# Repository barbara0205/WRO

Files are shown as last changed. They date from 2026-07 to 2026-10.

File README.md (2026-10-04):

# MechaMinds-WRO 2026 Future Engineers
# WRO Future Engineers - Engineering Documentation
<p align="center">
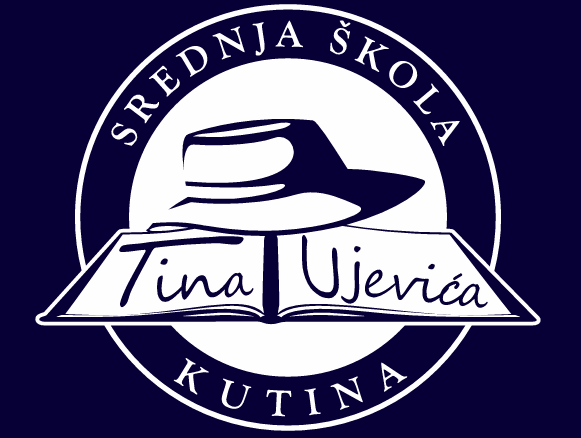
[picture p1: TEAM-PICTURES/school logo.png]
 
<br>
<em> Our school logo.</em>
</p>

## Team Members
- **Barbara Lukić**
- **Nadia Kravčuk**
- **Ivano Koren**

<p align="center">
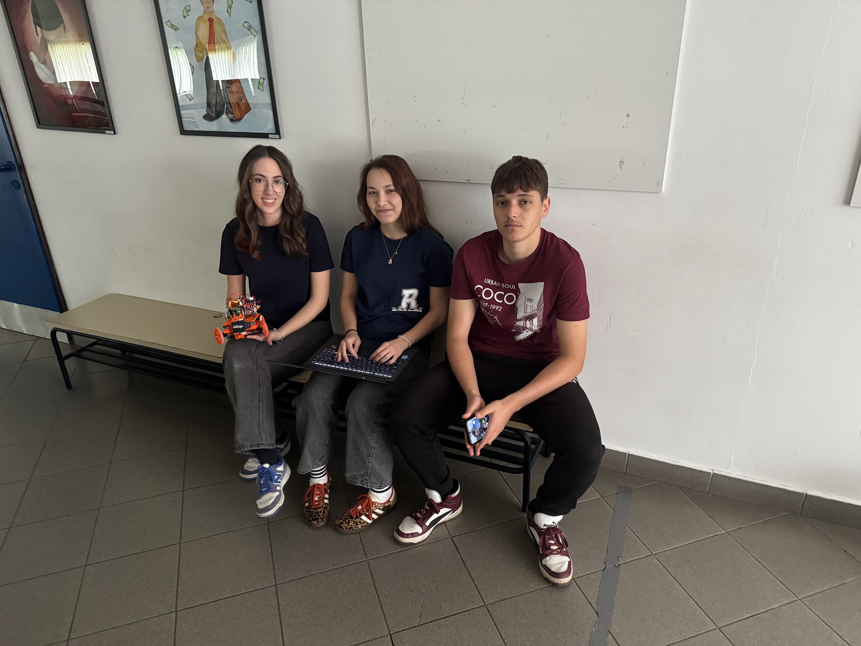
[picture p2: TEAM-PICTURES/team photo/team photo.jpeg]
  
</p>
<br>
<p align="center">
  <em>Team picture.</em>
</p>
<p align="center">
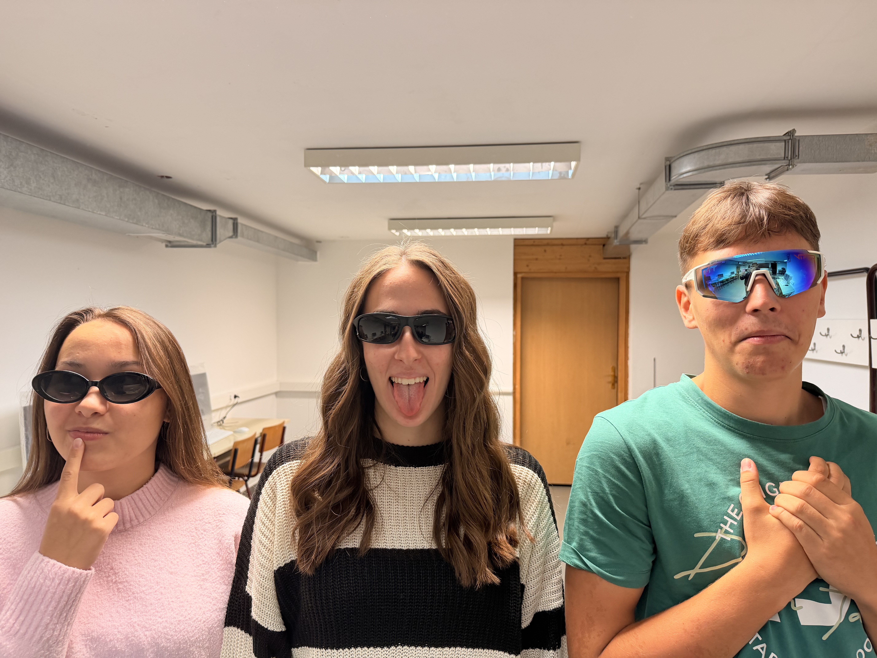
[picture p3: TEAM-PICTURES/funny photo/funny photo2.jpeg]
   
</p>
<br>
<p align="center">
  <em>Funny team picture.</em>
</p>

[Watch the introduction video](TEAM-PICTURES/video/video_mechaminds.mp4)

## Table of Contents

- [1. Project Overview](#1-project-overview)
- [2. Team](#2-team)
- [3. Vehicle Overview](#3-vehicle-overview)

- [4. Development History](#4-development-history)
  - [4.1 Version 1](#41-version-1)
  - [4.2 Version 2](#42-version-2)
  - [4.3 Version 3](#43-version-3)
  - [4.4 Version 4](#44-version-4)

- [5. Current Robot](#5-current-robot)
 
- [6. Mobility & Mechanical Design](#6-mobility--mechanical-design)
  - [6.1 Chassis](#61-chassis)
  - [6.2 Steering & Driving System](#62-steering--driving-system)
  - [6.3 Dimensions and Weight](#63-dimensions-and-weight)
  
- [7. Power & Sensor Architecture](#7-power--sensor-architecture)
  - [7.1 Motors](#71-motors)
  - [7.2 Sensors](#72-sensors)
  - [7.3 Camera](#73-camera)
  - [7.4 Wiring Diagram](#74-wiring-diagram)
  - [7.5 Power](#75-power)
  - [7.6 ON/OFF Button](#76-onoff-button)
  
- [8. Software Architecture](#8-software-architecture)
  - [8.1 Overview](#81-overview)
  - [8.2 Code](#82-code)
  - [8.3 Open Challenge Strategy](#83-open-challenge-strategy)
  - [8.4 Obstacle Challenge Strategy](#84-obstacle-challenge-strategy)
    
- [9. Engineering Decisions](#9-engineering-decisions)
  - [9.1 Major Problems and Solutions](#91-major-problems-and-solutions)

- [10. Testing & Results](#10-testing--results)

- [11. Components / Bill of Materials](#11-components--bill-of-materials)

- [12. Build & Reproduction Guide](#12-build--reproduction-guide)
  - [12.1 Parts](#121-parts)
  - [12.2 Assembly](#122-assembly)

- [13. Repository Structure](#13-repository-structure)
- [14. Engineering Journal](#14-engineering-journal)

## 1. Project Overview
Our project is an autonomous vehicle that can navigate the competition field, detect and avoid obstacles, follow the track and make real time decisions without human intervention.

<p align="right">
  <a href="#table-of-contents">⬆ Back to Table of Contents</a>
</p>

## 2. Team
We are the Croatian robotics team **MechaMinds** and our names are **Barbara Lukić**, **Ivano Koren** and **Nadia Kravčuk**. We come from Tin Ujević High School in Kutina. Our mentor's name is Damir Petravić. Together we worked on the design of the robot, programming and testing our robot.

<p align="right">
  <a href="#table-of-contents">⬆ Back to Table of Contents</a>
</p>

## 3. Vehicle Overview
| Specification | Value |
|---|---|
| Length | 18 cm |
| Width | 17.5 cm |
| Height | 15.5 cm |
| Weight | 0.876 kg |
| Drive type | Rear-wheel drive |
| Steering type | Ackermann steering | ---Servo-controlled front steering???
| Main controller | Raspberry Pi 5 Model (B Rev1.1) |
| Programming language | C++ |
| Main sensors | MRMS LIDAR 2 m (VL53L0CX), CAN Bus |
| Camera | Raspberry Pi Camera Module 3 |
| Power source | Turnigy 5S LiPo, 18.5 V, 5000 mAh |

<p align="right">
  <a href="#table-of-contents">⬆ Back to Table of Contents</a>
</p>

## 4. Development history 
Our robot went through several major design changes during the development process. 
### 4.1. Version 1 
**About the robot** 
  - Our first robot was a custom-built vehicle made using 3D-printed and hand-built parts. It had several distance sensors that helped us test the robot.

**Main problem** 
  - The robot was not reliable enough to complete three laps so we decided to change the robot for better performance.

| Front | Rear |
|---|---|
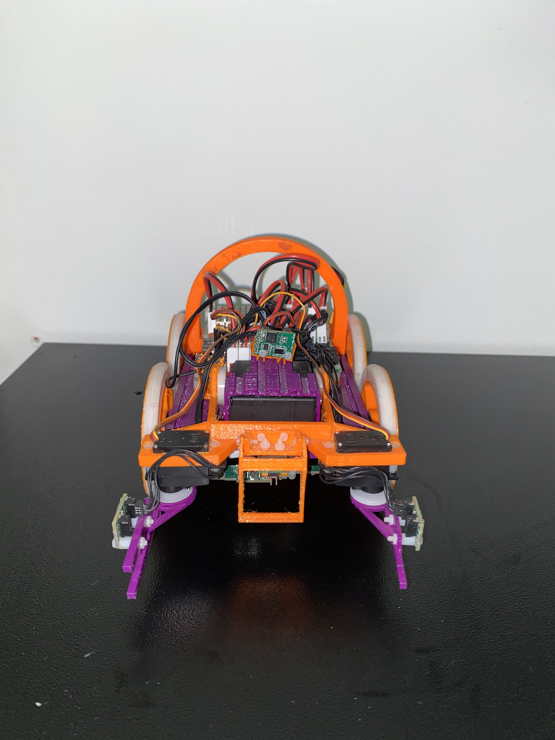
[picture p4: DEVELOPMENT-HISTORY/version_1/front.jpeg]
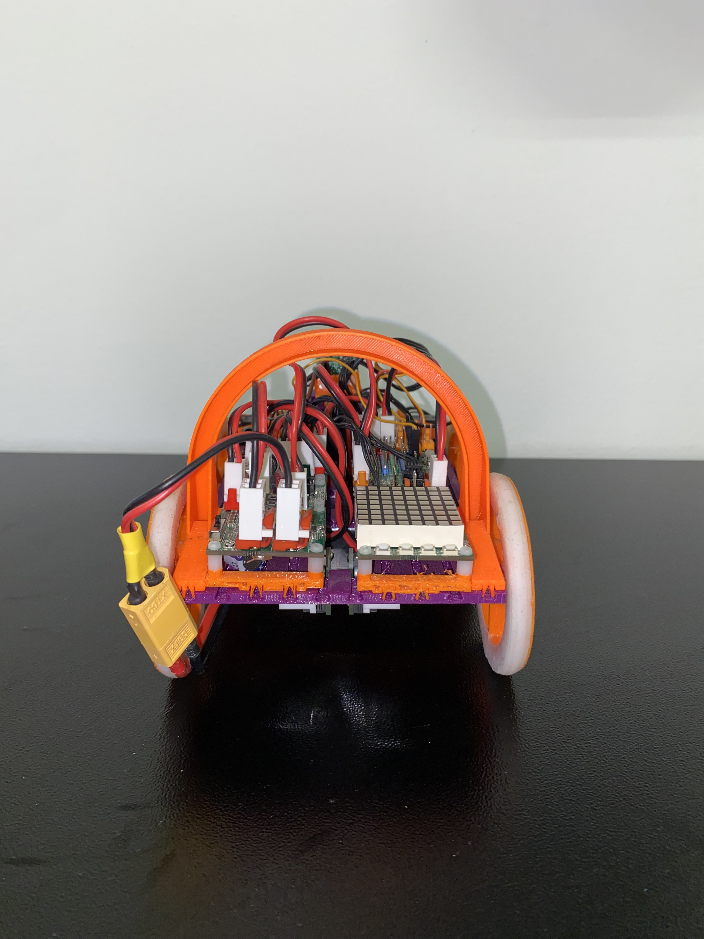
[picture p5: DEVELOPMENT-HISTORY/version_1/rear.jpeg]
|  |  |

| Left | Right |
|---|---|
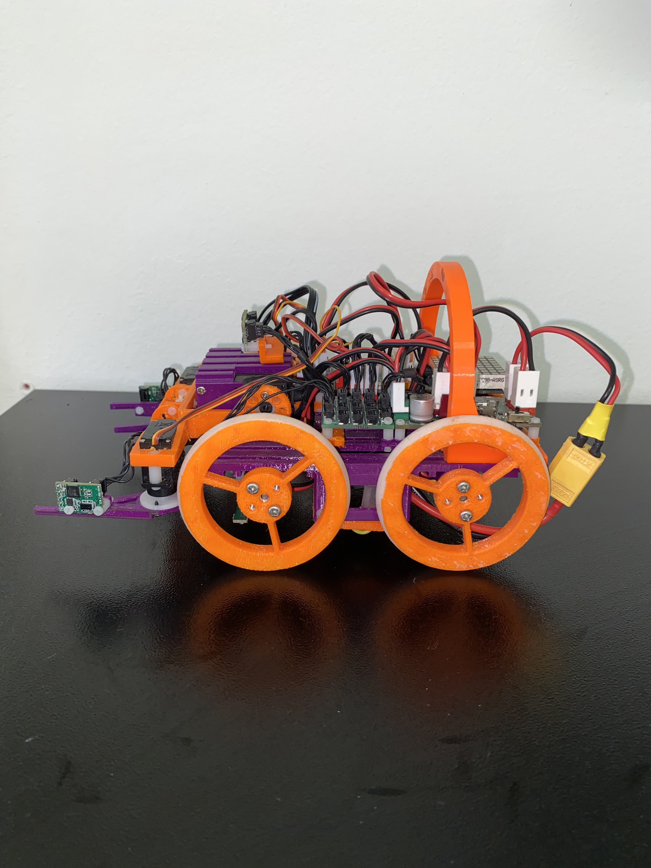
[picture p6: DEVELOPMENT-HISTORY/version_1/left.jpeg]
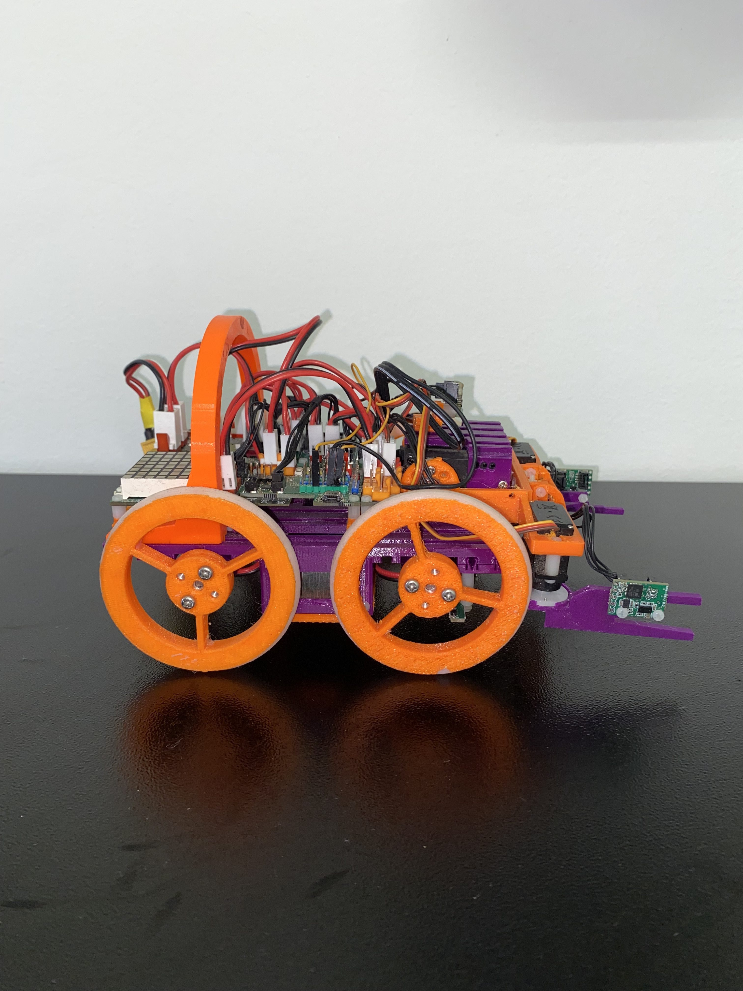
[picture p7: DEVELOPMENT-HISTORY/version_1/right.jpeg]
|  |  |

| Top | Bottom |
|---|---|
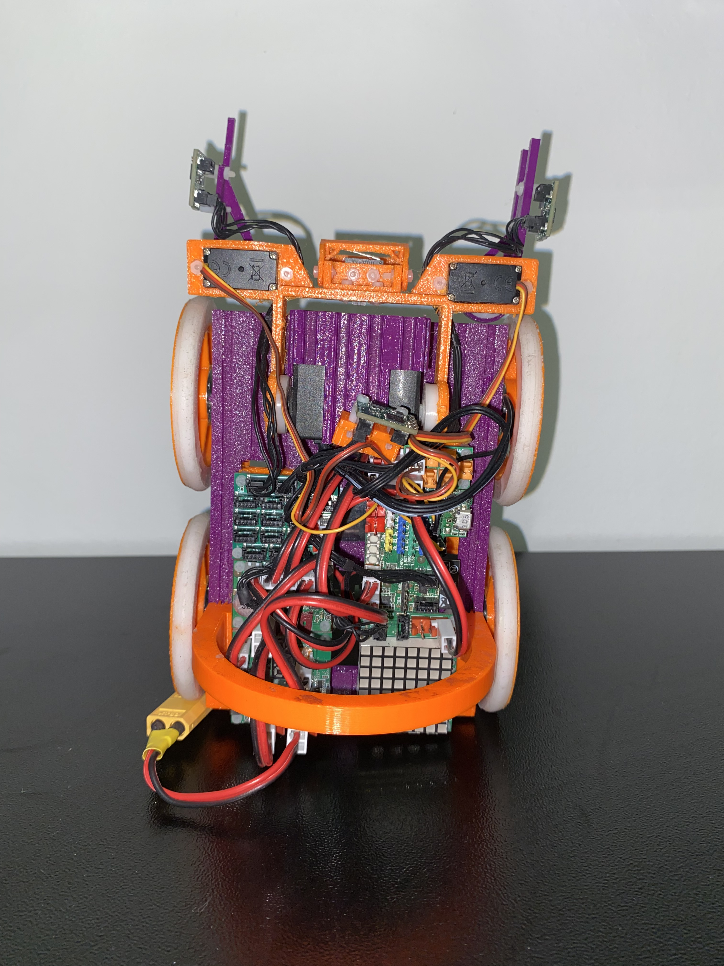
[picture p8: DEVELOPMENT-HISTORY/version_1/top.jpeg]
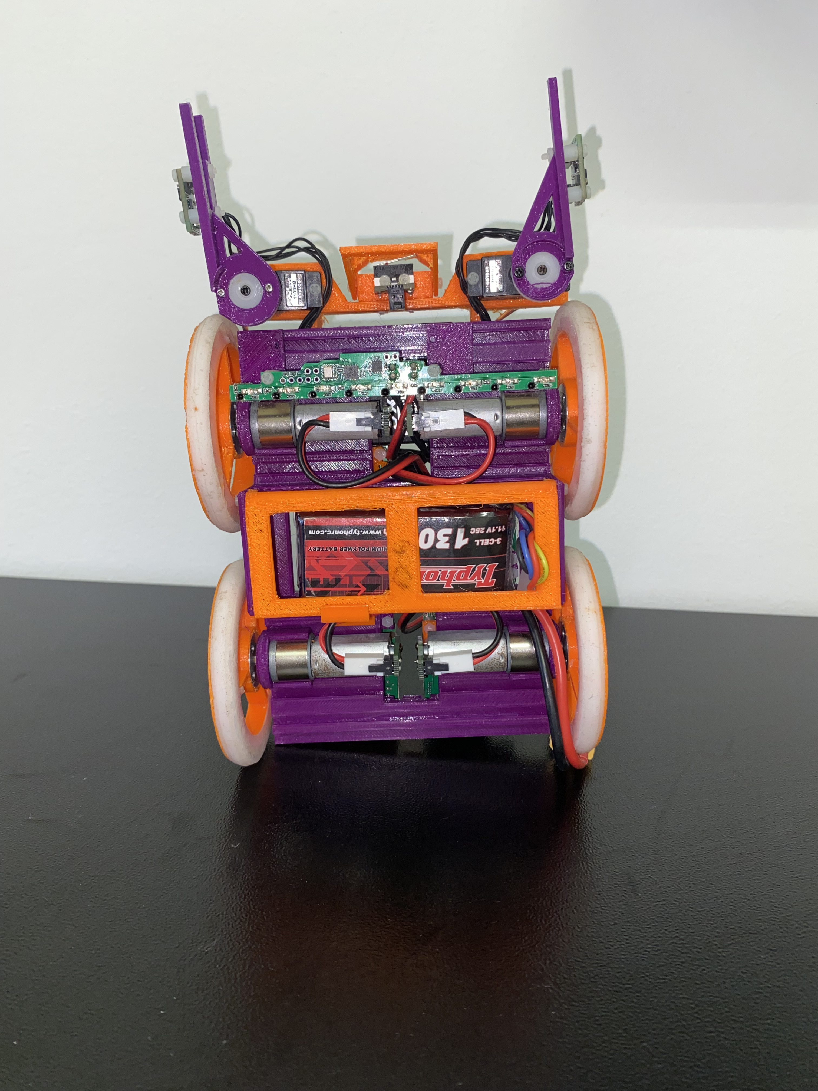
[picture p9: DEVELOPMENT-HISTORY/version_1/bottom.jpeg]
|  |  |

<p align="right">
  <a href="#table-of-contents">⬆ Back to Table of Contents</a>
</p>

### 4.2. Version 2
**About the robot**
- This robot was an upgraded version of the first one, it had a camera and several distance sensors.
  
**Main problem**
- All year we have been working on this robot, about one month before the competition we started having problems connecting the robot to Wi-Fi, it started crashing and we tried to find a solution before the competition but we did not succeed.

| Front | Rear |
|---|---|
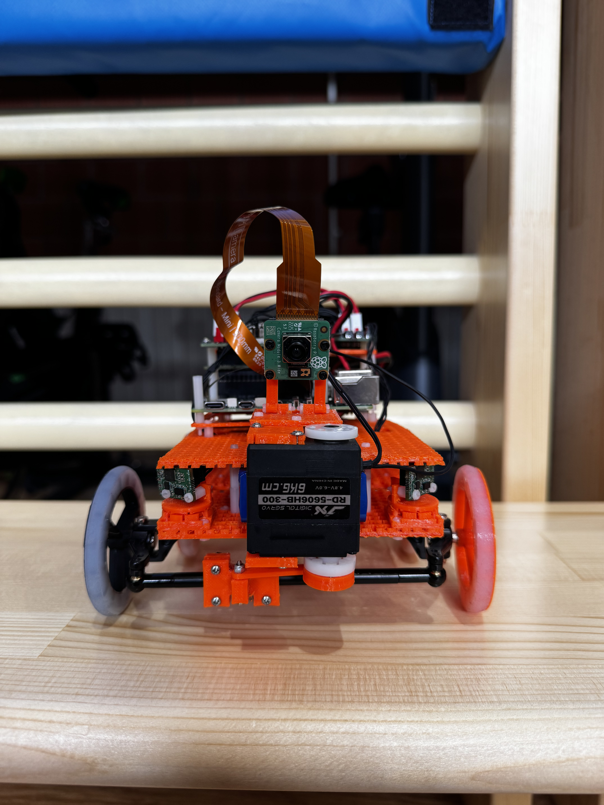
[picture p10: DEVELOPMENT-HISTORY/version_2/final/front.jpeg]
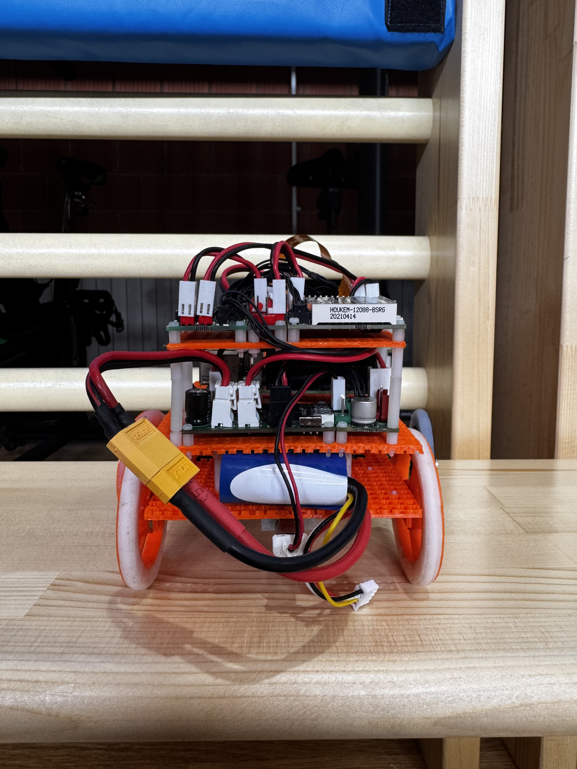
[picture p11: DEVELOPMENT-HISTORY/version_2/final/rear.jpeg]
|  |  |

| Left | Right |
|---|---|
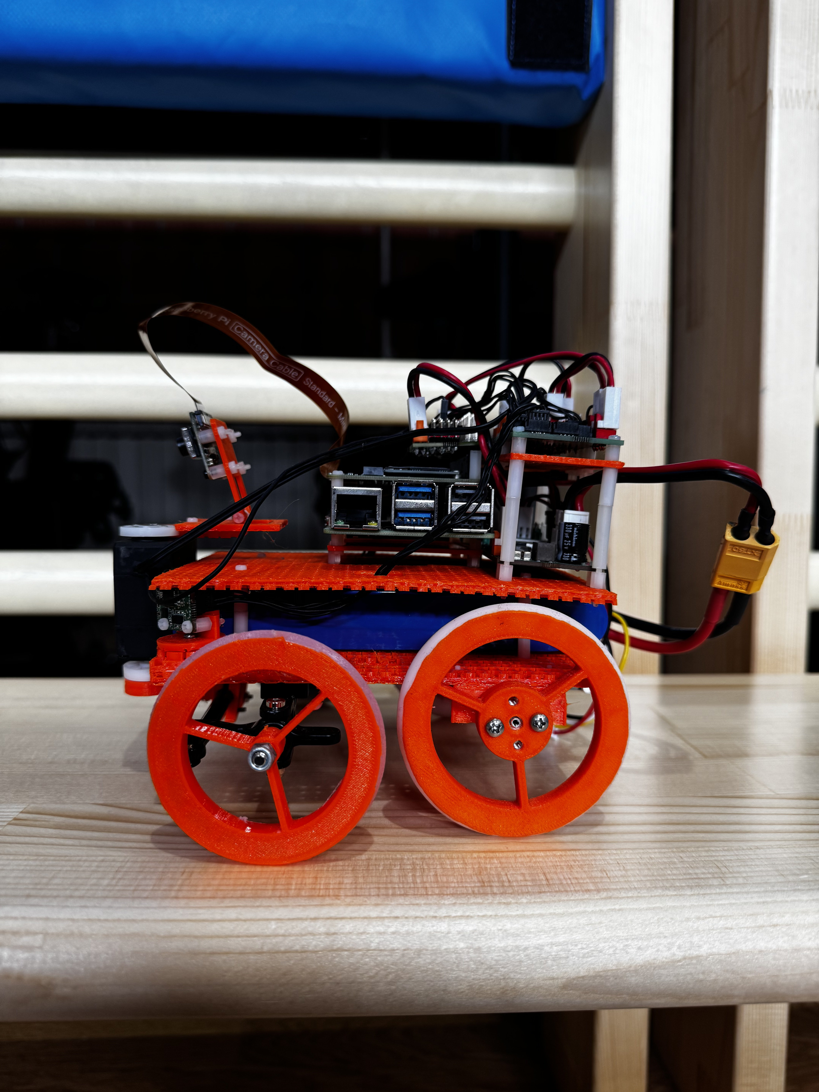
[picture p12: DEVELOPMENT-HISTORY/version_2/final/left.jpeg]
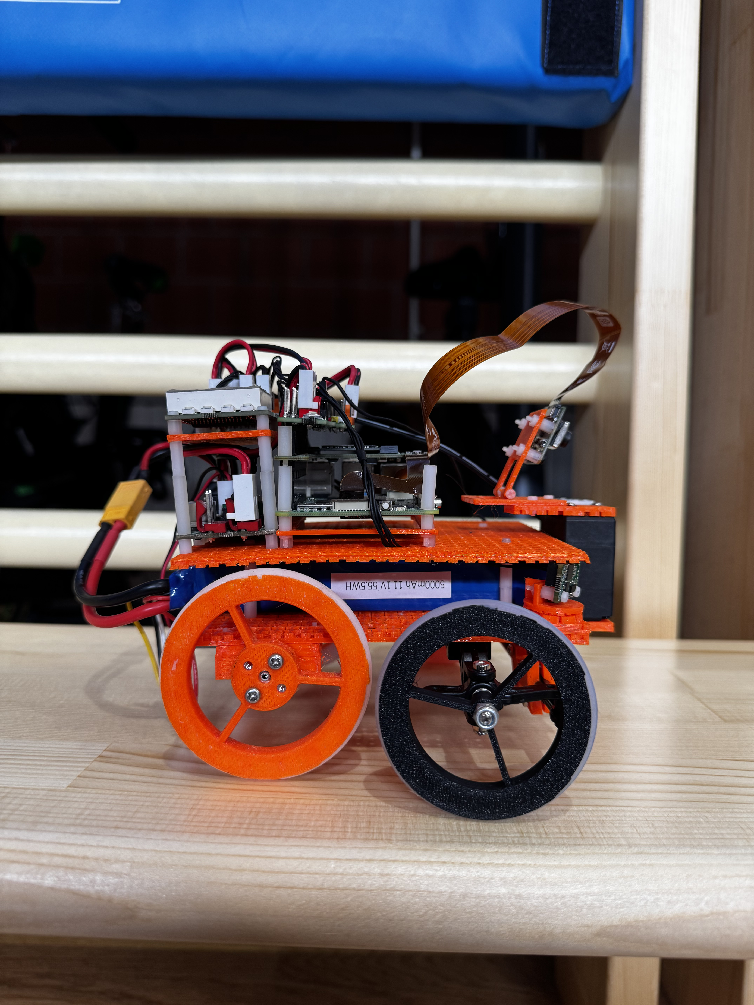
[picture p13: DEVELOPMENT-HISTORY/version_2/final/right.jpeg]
|  |  |

| Top | Bottom |
|---|---|
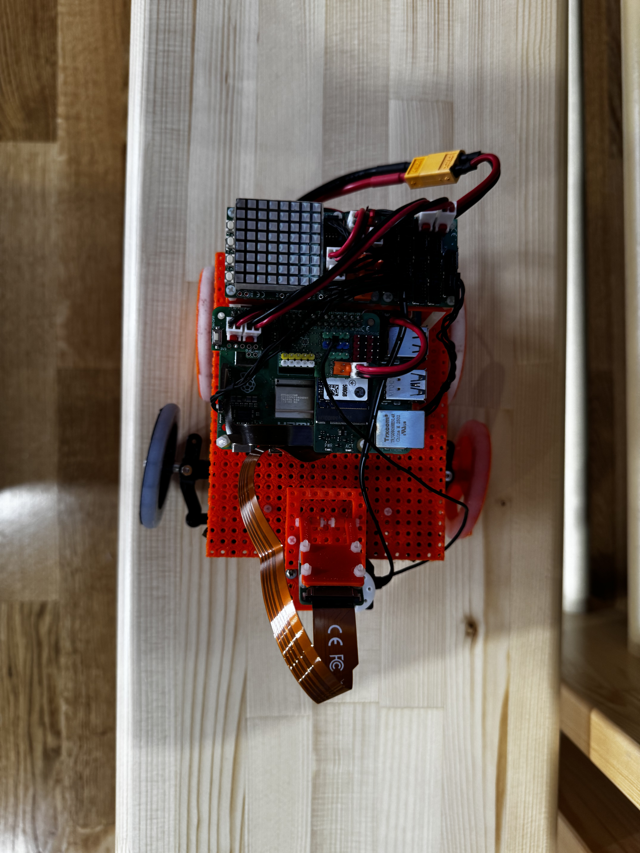
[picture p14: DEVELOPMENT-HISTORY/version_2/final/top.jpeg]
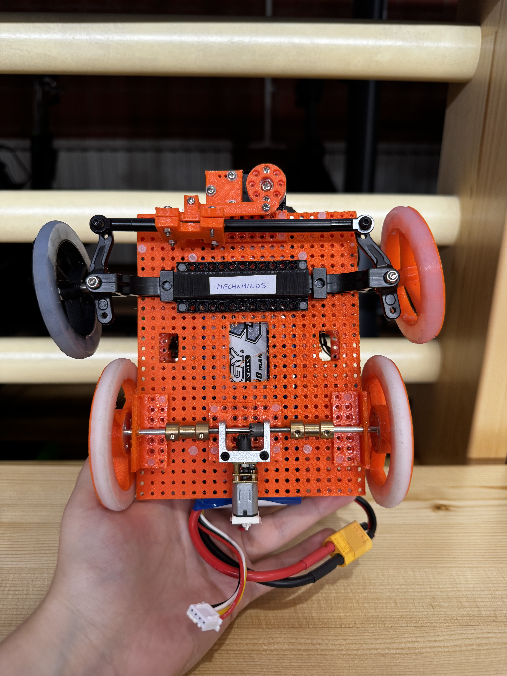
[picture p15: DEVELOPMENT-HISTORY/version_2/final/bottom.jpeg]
|  |  |

<p align="right">
  <a href="#table-of-contents">⬆ Back to Table of Contents</a>
</p>

### 4.3. Version 3
**About the robot**
- This robot was built out of LEGO, it represents a model of a Ford car.

**Main problem**
- The robot had a problem turning its wheels because of the design, so it could not complete even one lap, because of this we had to completely redesign it.

| Front | Rear |
|---|---|
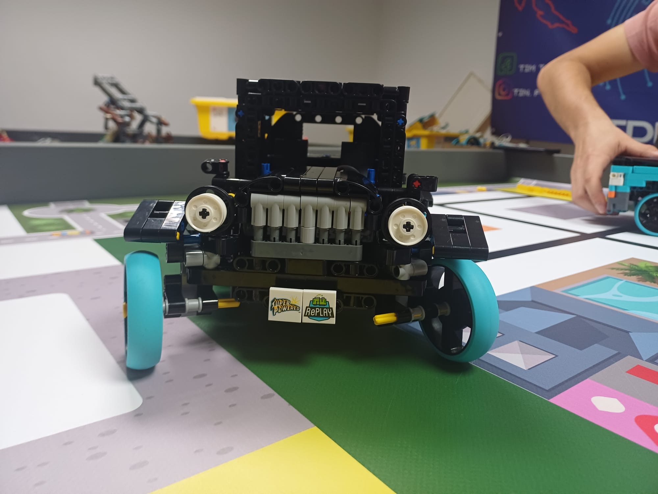
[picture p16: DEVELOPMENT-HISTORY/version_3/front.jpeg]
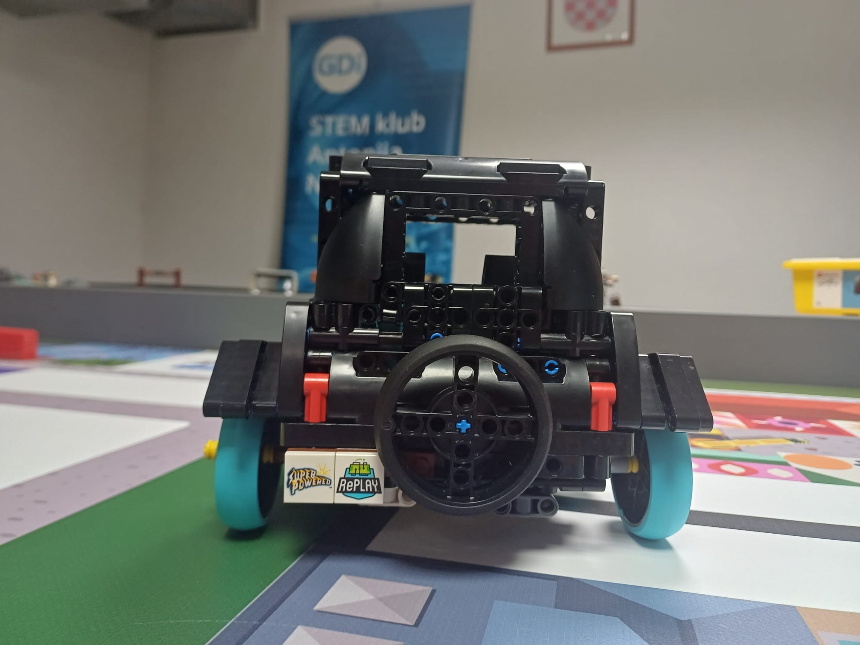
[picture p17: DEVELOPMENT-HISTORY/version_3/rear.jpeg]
|  |  |

| Left | Right |
|---|---|
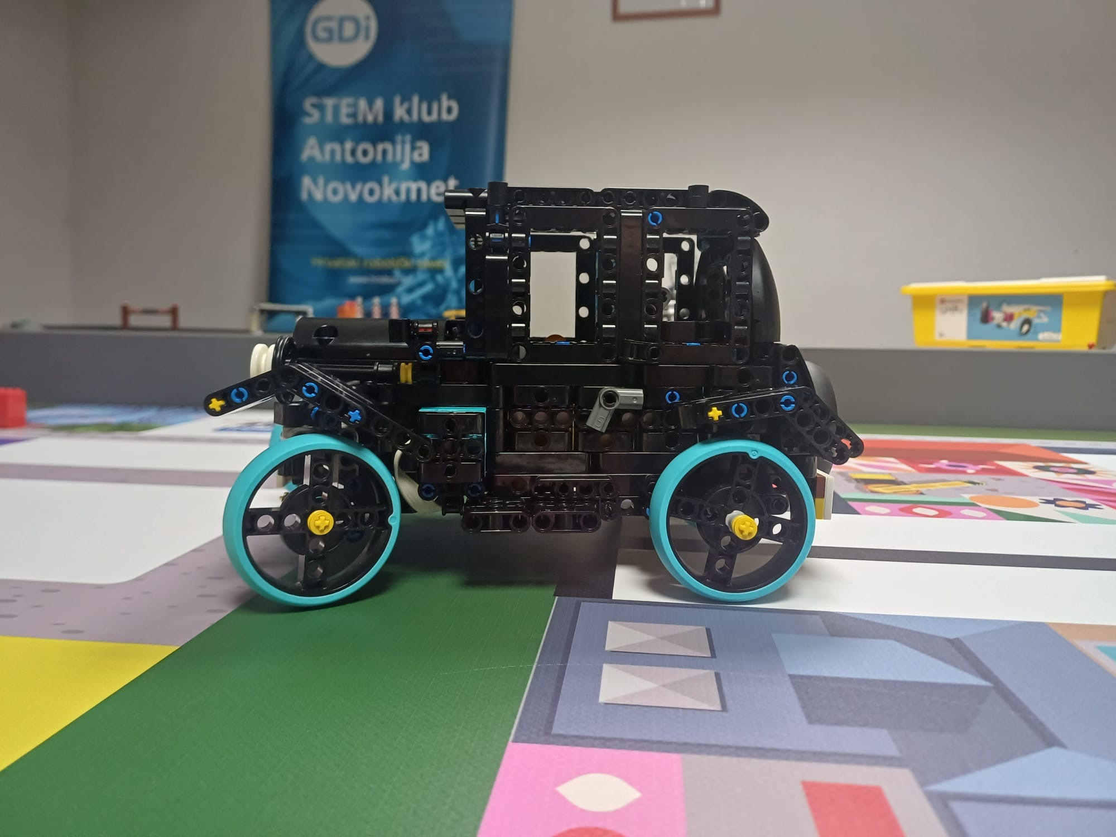
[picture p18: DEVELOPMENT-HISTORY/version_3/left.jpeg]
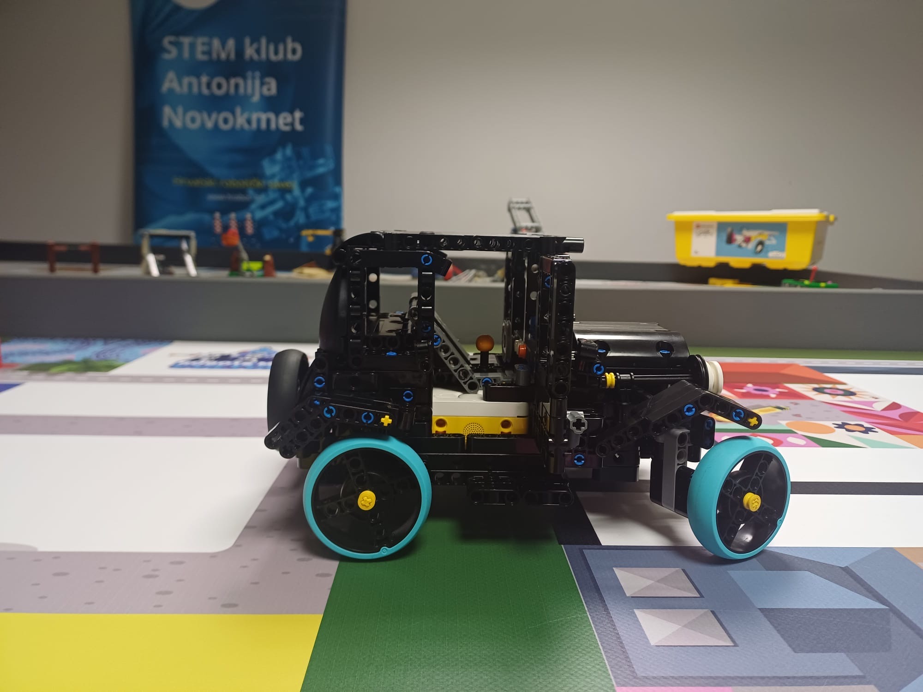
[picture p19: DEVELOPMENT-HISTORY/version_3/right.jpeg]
|  |  |

| Top | Bottom |
|---|---|
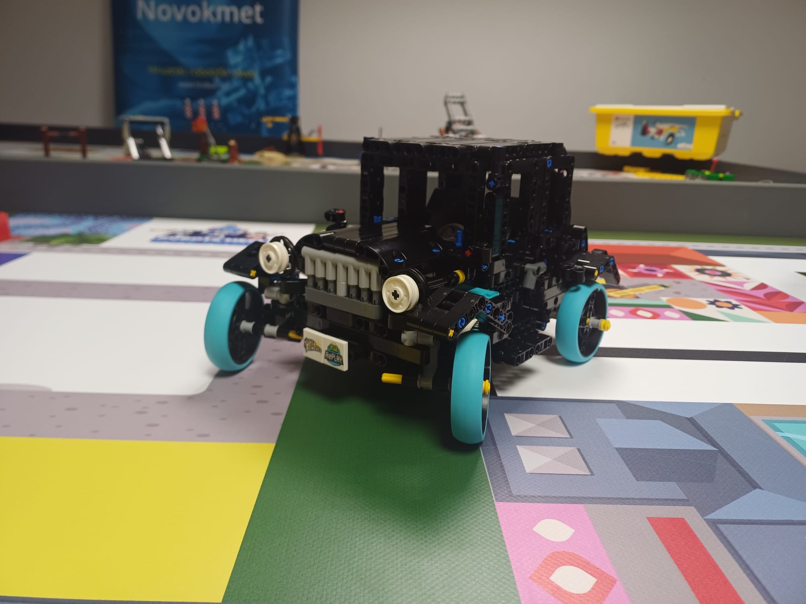
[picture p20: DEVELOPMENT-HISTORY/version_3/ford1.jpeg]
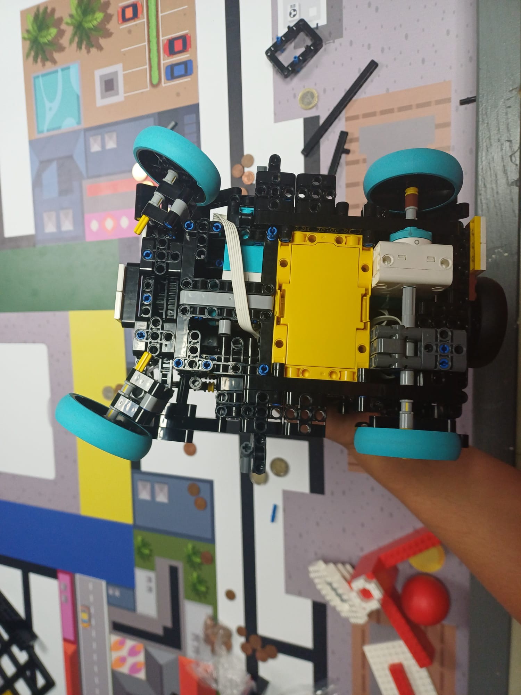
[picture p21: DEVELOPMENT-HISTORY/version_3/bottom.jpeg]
|  |  |

<p align="right">
  <a href="#table-of-contents">⬆ Back to Table of Contents</a>
</p>

### 4.4. Version 4
**About the robot**
- This was our final robot that we went to the competition with, it was also built out of lego bricks, it worked with the help of distance sensors.
  
**Main problem**
- Although we went to the competition with this robot it still had a few flaws. The LEGO sensors that we used to measure distance were not able to detect walls from sufficient distance so the robot couldn't complete even one lap.

| Front | Rear |
|---|---|
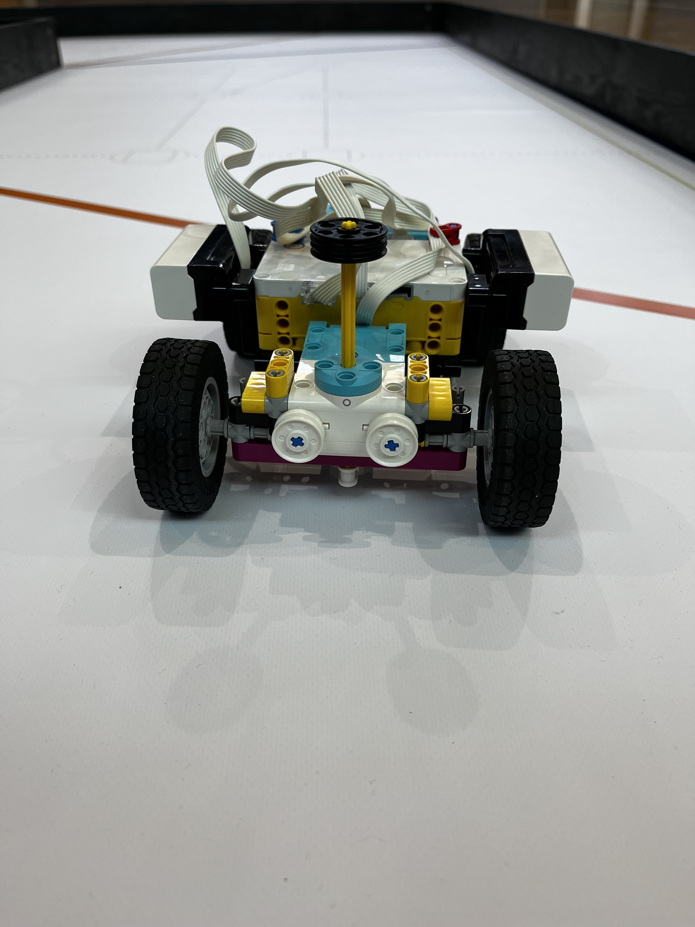
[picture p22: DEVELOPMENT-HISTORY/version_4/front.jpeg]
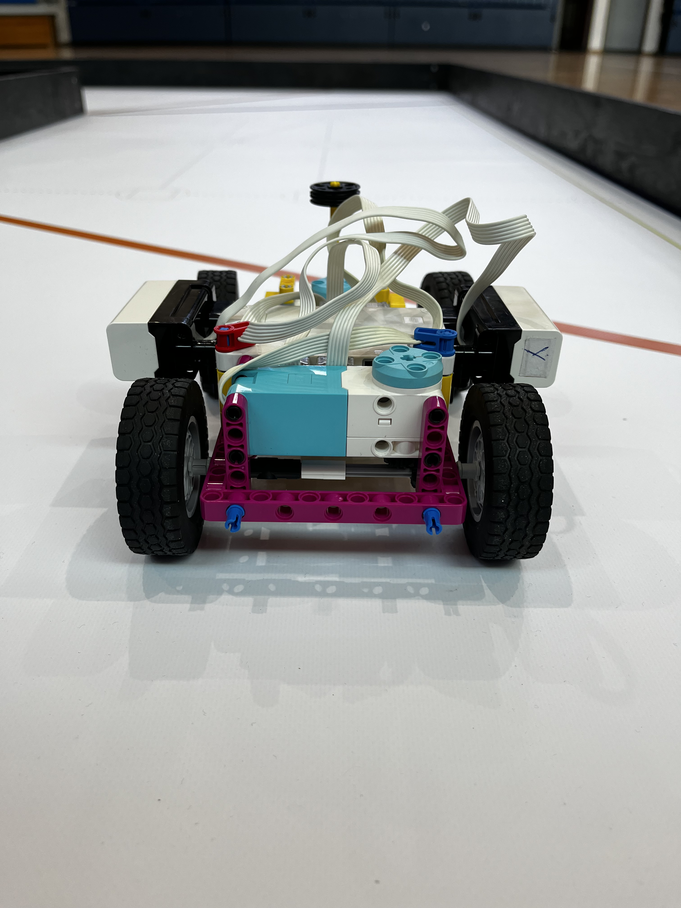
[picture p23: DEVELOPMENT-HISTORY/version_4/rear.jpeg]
|  |  |

| Left | Right |
|---|---|
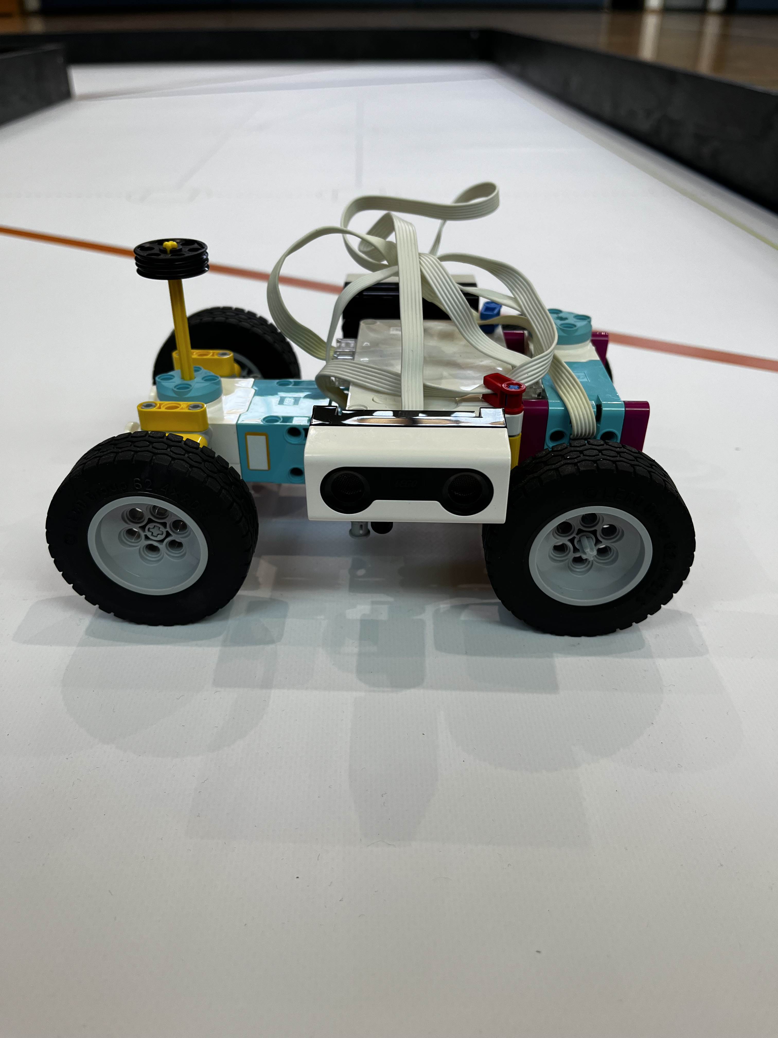
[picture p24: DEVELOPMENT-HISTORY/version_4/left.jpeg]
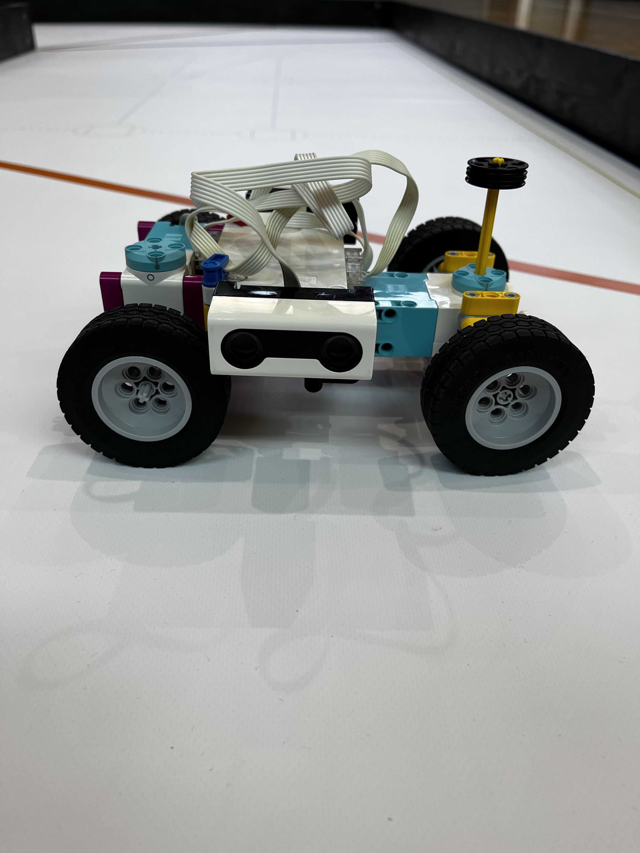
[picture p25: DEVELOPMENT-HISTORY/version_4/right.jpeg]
|  |  |

| Top | Bottom |
|---|---|
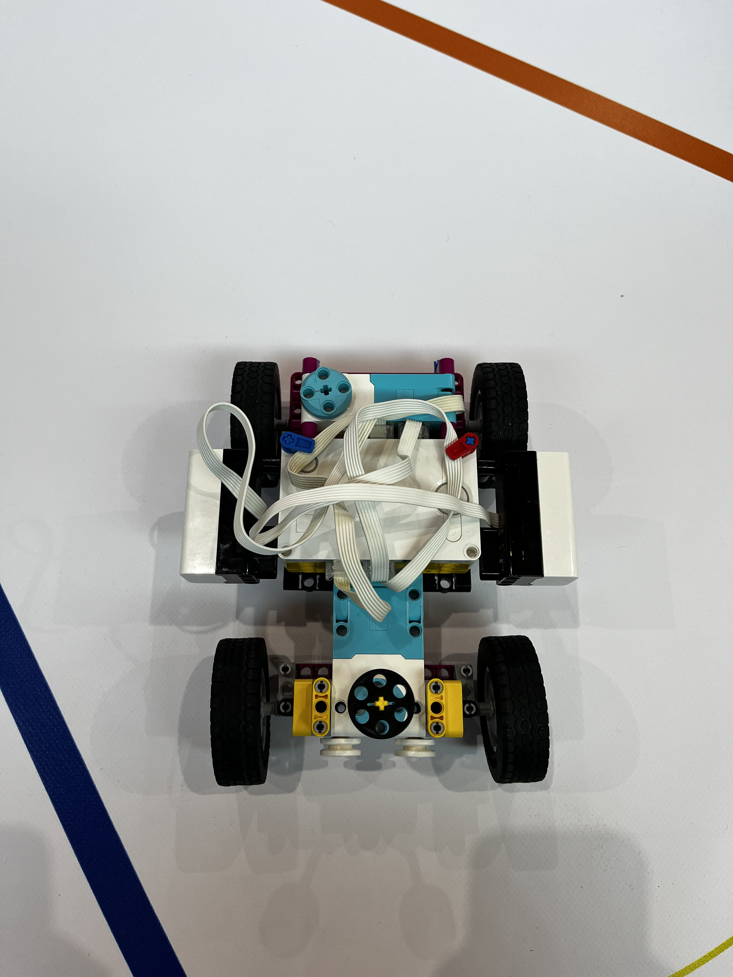
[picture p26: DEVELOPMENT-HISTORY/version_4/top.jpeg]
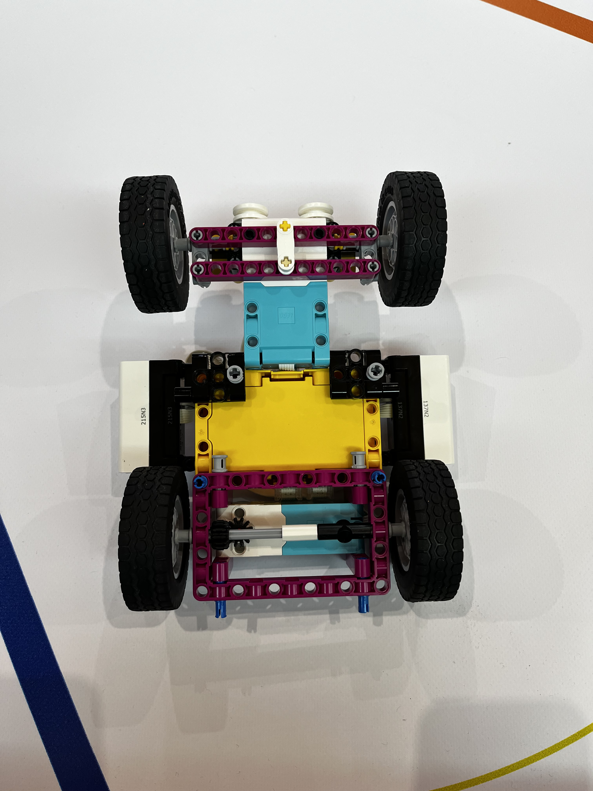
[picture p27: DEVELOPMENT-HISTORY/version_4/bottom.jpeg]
|  |  |

<p align="right">
  <a href="#table-of-contents">⬆ Back to Table of Contents</a>
</p>

## 5. Current Robot
The robot we will use for the competition in Zagreb is [4.2 Version 2](#42-version-2). Although this version originally had problems with an unstable Wi-Fi connection, the connection issue was later solved [9.1 Major Problems and Solutions](#91-major-problems-and-solutions) This robot can now avoid obstacles and track walls using two distance sensors that are placed on each side of the robot. 

The robot uses a four-wheel chassis with rear-wheel drive and servo-controlled front steering.

For navigation, the robot uses LiDAR distance sensors positioned near the front of the chassis. They measure the distance from nearby walls and allow the robot to follow the track, maintain a safe distance from the walls and avoid collisions.

A Raspberry Pi Camera Module 3 is mounted at the front of the robot. The camera is used to detect colored obstacles and other important features of the competition field. By combining camera-based vision with LiDAR distance measurements, the robot can make navigation decisions in real time.

| Front | Rear |
|---|---|
|  |  |

| Left | Right |
|---|---|
|  |  |

| Top | Bottom |
|---|---|
|  |  |

<p align="right">
  <a href="#table-of-contents">⬆ Back to Table of Contents</a>
</p>

| Front | Rear |
|---|---|
|  |  |

| Left | Right |
|---|---|
|  |  |

| Top | Bottom |
|---|---|
|  |  |

<p align="right">
  <a href="#table-of-contents">⬆ Back to Table of Contents</a>
</p>

## 6. Mobility & Mechanical Design
### 6.1 Chassis

#### Chassis Overview
Our current vehicle uses a four-wheel chassis, the chassis provides the mechanical base for the drive system, steering mechanism, sensors and processing hardware. The design was developed with stability, compact dimensions and reliable steering in mind.

#### Component Placement
The electronic components are arranged on several levels above the main chassis plate. The battery is positioned low inside the chassis to keep the center of gravity as low as possible, while the processing and control electronics are placed above it. The camera is placed at the front of the robot on a dedicated 3D-printed support so it could have good visibility of the field. The distance sensors are positioned near the front of the vehicle so that they can detect the surrounding walls during navigation.

- Main controller: on top of the robot
- Battery: inside the chassis
- Drive motor: in the back, underneath the chassis
- Steering servo: in the front, underneath the chasis
- Sensors: in the front, inside the chassis
- Camera: the front of the robot

<p align="right">
  <a href="#table-of-contents">⬆ Back to Table of Contents</a>
</p>

### 6.2 Steering & Driving System

The vehicle uses a servo-controlled front steering mechanism. A steering servo placed at the front of the chassis moves a mechanical linkage that connects the two front wheels. Instead of controlling the left and right wheels with separate motors, both front wheels are mechanically linked and change direction together. This provides car-like steering while the rear wheels make the robot move forward. The steering components are mounted directly to the 3D-printed chassis, which allowed us to adjust the geometry and mounting positions during development. The two rear wheels are connected by a metal rod and do not turn left or right, so they keep the robot moving straight. The motor is connected to the battery and provides the power needed to move the robot. This simple system allows the robot to move forward in a straight line.

<p align="center">
  
</p>

<p align="center">
  <em>Front steering mechanism and mechanical linkage.</em>
</p>

<p align="right">
  <a href="#table-of-contents">⬆ Back to Table of Contents</a>
</p>

### 6.3 Dimensions and Weight

| Measurement | Value |
|---|---|
| Length | 180 mm |
| Width | 175 mm |
| Height | 155 mm |
| Weight | 0.876 kg |
| Wheelbase | 100 mm |
| Front track width | 175 mm |
| Rear track width | 170 mm |
| Front wheel diameter | 60 mm |
| Rear wheel diameter | 65 mm |

<p align="right">
  <a href="#table-of-contents">⬆ Back to Table of Contents</a>
</p>

## 7. Power & Sensor Architecture
### 7.1 Motors

The robot is powered by a single ML-R BDC N20 micro brushed DC motor. It operates at 12V DC with a low-power profile, ensuring high efficiency for battery-powered operation. The integrated 1:100 gear ratio provides high output torque within a compact 12 mm form factor. This motor serves as the primary drive source for the robot's propulsion mechanism.

<p align="left">
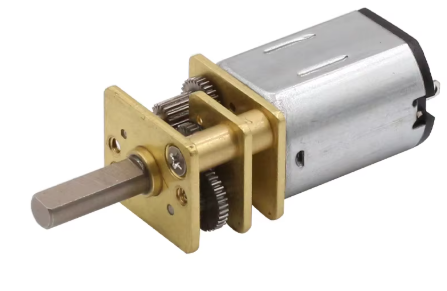
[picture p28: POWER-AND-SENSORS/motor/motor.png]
ML-R BDC N20 Motor
  
</p>

<p align="right">
  <a href="#table-of-contents">⬆ Back to Table of Contents</a>
</p>

### 7.2 Sensors

The robot uses MRMS VL53L0CX LiDAR sensors to measure the distance to nearby obstacles. The sensors have a specified range of up to 2 m and communicate with the rest of the system via CAN Bus. Each robot is equipped with three LiDAR sensors, allowing distance measurements in multiple directions. The collected data can be used for obstacle detection, navigation, and collision avoidance. Both LiDARSs are placed at the front of the robot, each on one side, between two chassis and at the angle of 45° so they wouldn't be too high nor too low to not be able to detect walls from the side and from the front.

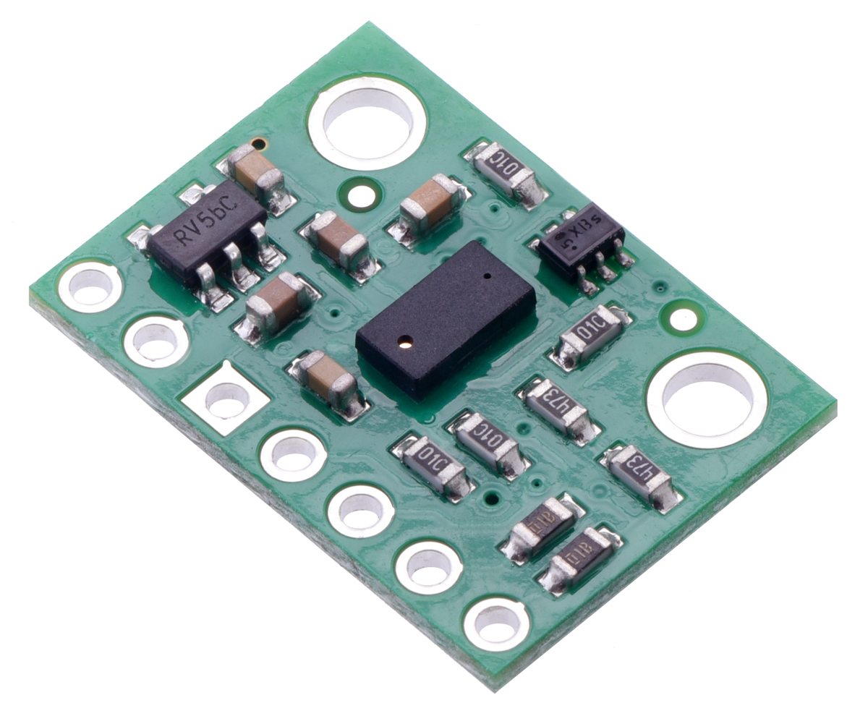
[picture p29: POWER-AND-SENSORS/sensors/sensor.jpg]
 

<p align="right">
  <a href="#table-of-contents">⬆ Back to Table of Contents</a>
</p>

###  7.3 Camera

The robot uses a Raspberry Pi Camera Module 3 for visual perception of its surroundings. The camera is connected to the Raspberry Pi 5 and can be used to capture images and video for further processing. It can support tasks such as line detection, object recognition, marker detection, and navigation. The camera complements the LiDAR sensors by providing visual information that distance sensors alone cannot provide.

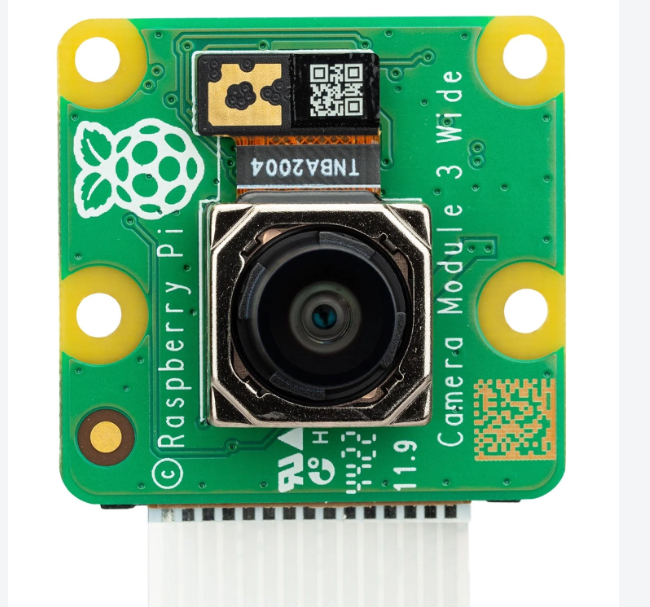
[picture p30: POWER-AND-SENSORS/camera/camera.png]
 

<p align="right">
  <a href="#table-of-contents">⬆ Back to Table of Contents</a>
</p>

### 7.4 Wiring Diagram

<p>
  This diagram illustrates the robot's physical structure and highlights the core components, 
  demonstrating how the essential systems and connections are wired together.
</p>

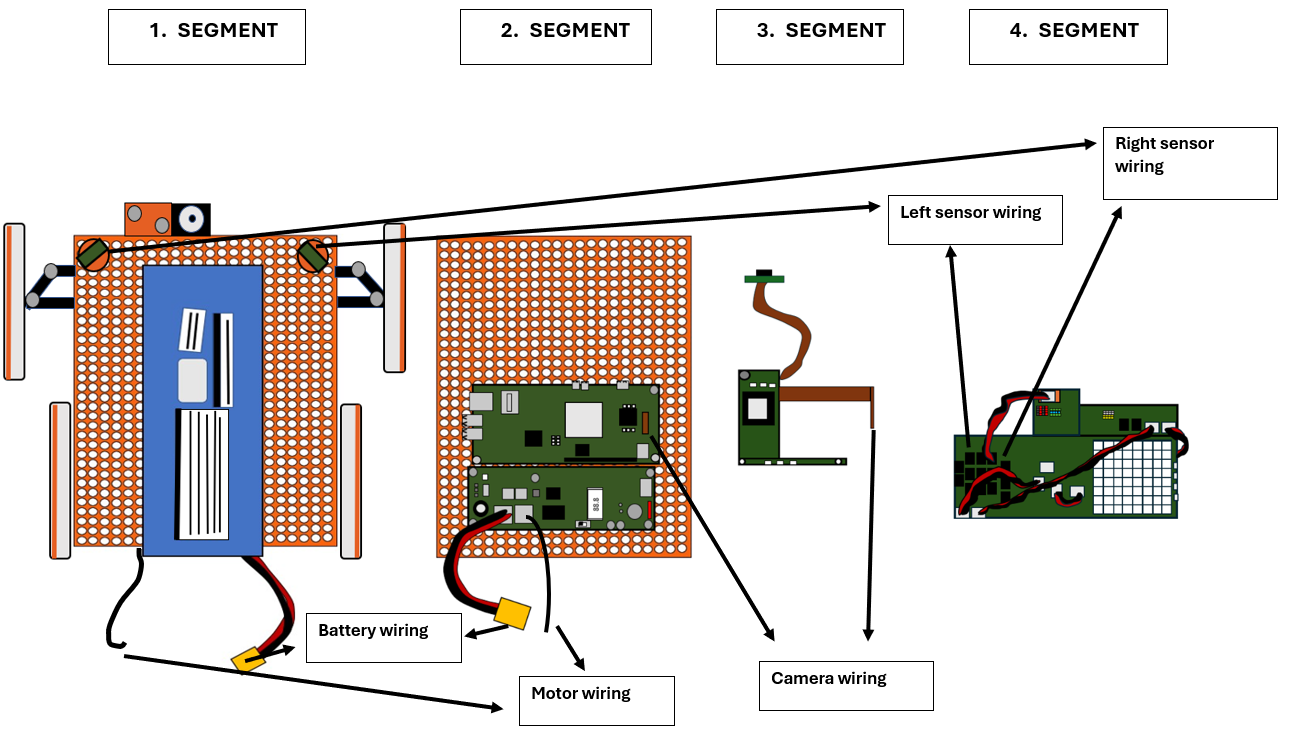
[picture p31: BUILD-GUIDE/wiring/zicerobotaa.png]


<p align="right">
  <a href="#table-of-contents">⬆ Back to Table of Contents</a>
</p>

### 7.5 Power
#### Battery

Our robot is powered by a Turnigy 5.0 High Discharge LiPo battery. 
The battery was selected to provide sufficient voltage, capacity and 
current for the robot's motors and electronic components.

#### Specifications

| Parameter | Value |
|---|---|
| Battery type | LiPo (Lithium Polymer) |
| Configuration | 5S |
| Nominal voltage | 18.5 V |
| Capacity | 5000 mAh (5.0 Ah) |
| Discharge rating | 20–30C |
| Discharge current | 150 A |
| Manufacturer | Turnigy |
| Model | Turnigy 5.0 |
| Main connector | High-current connector |
| Balance connector | 5S balance connector |

We chose this battery because our robot requires a power source capable of 
supplying high current to the motors while maintaining a stable voltage.

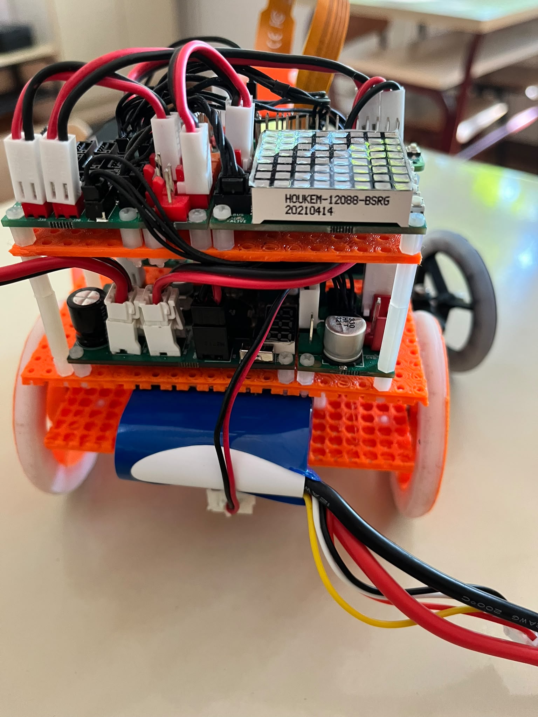
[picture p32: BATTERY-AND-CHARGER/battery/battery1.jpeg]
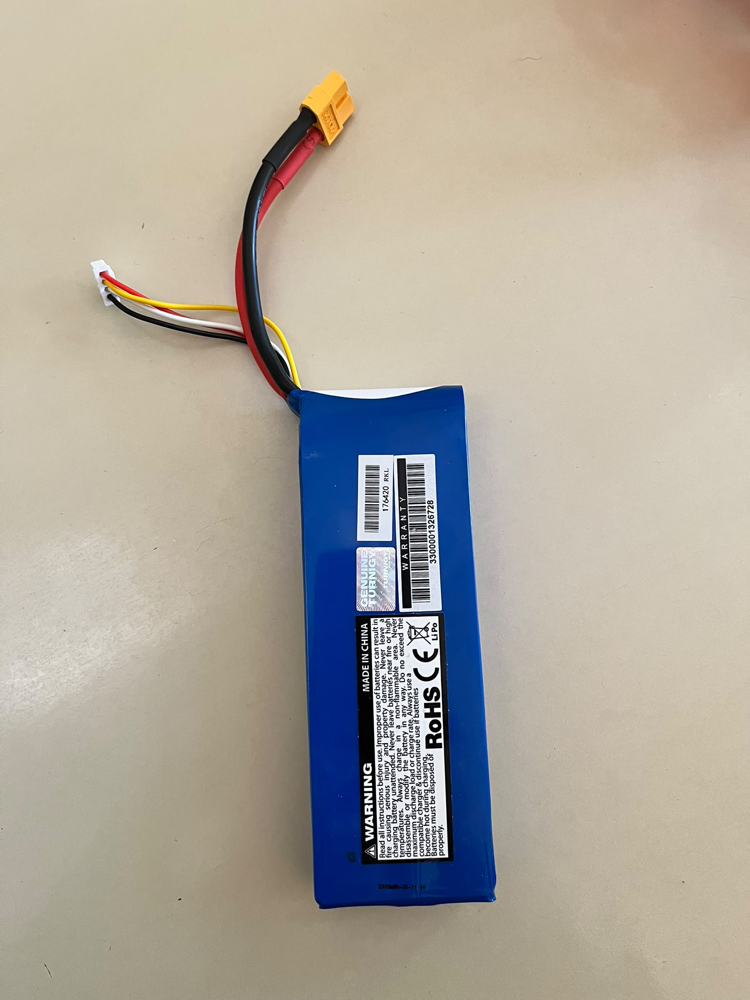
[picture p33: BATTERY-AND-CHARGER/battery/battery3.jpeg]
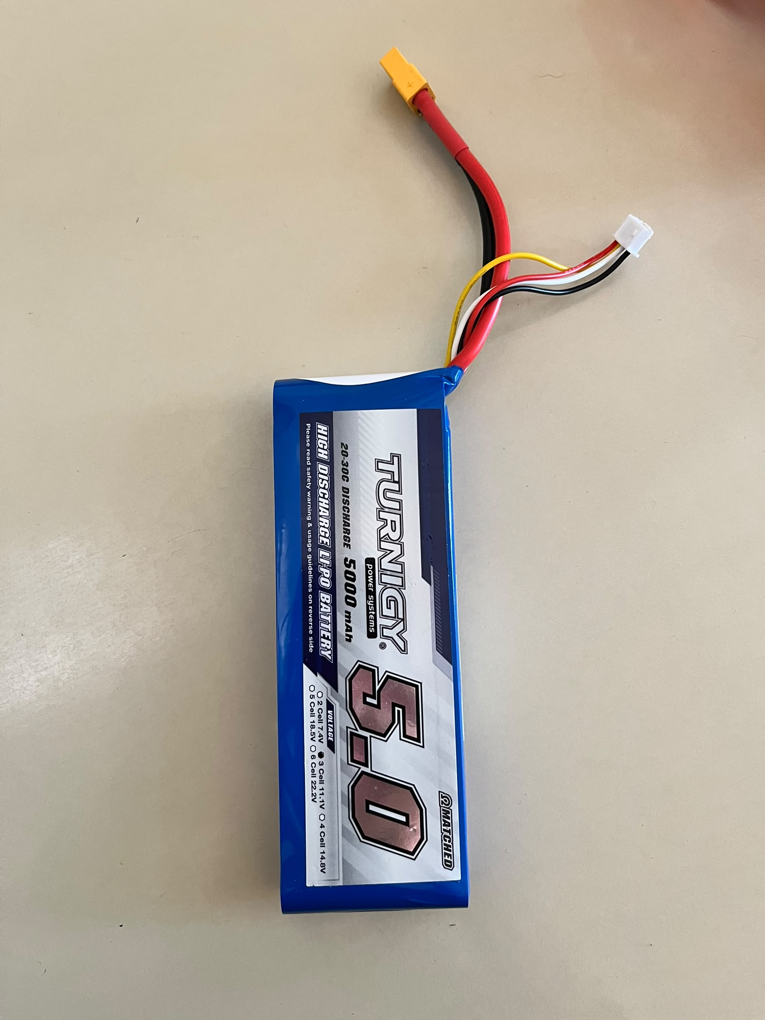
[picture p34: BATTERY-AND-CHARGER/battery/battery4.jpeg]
  
#### Charger

The robot uses a B6 LiPro 80W Balance Charger to charge the LiPo battery. It supports 1–6 cell LiPo batteries and includes a balance function to keep the voltage of the individual cells equal during charging.

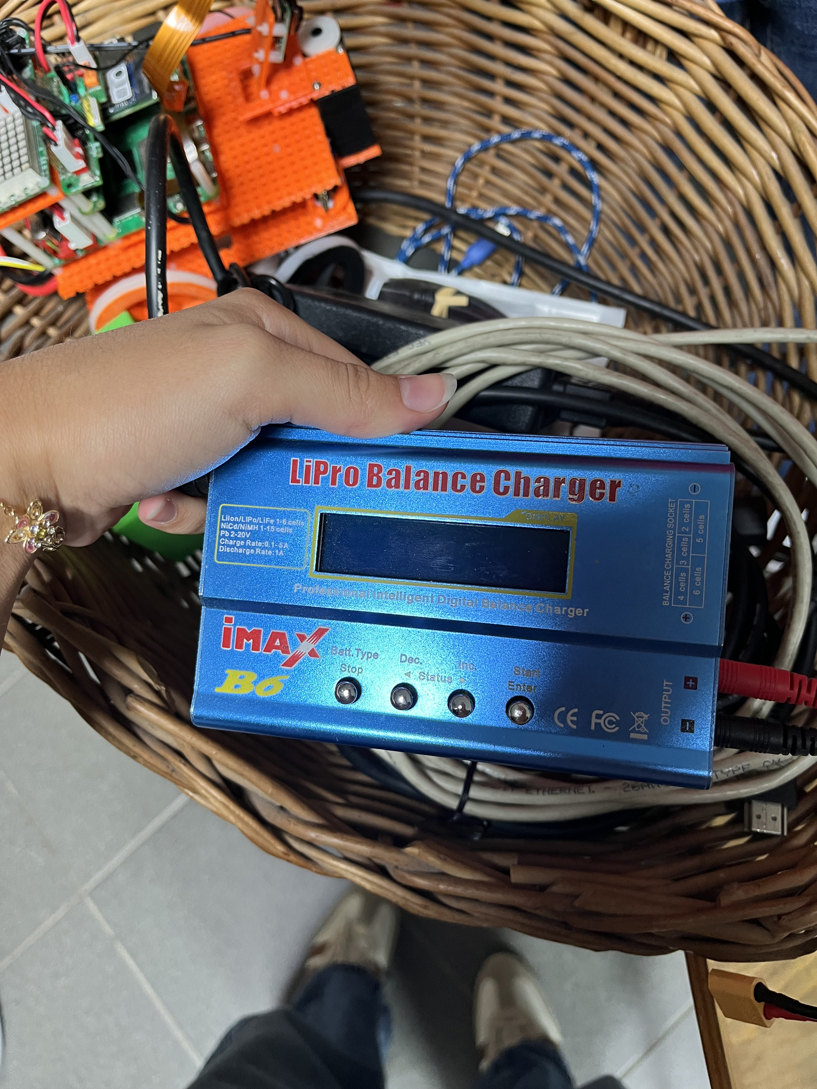
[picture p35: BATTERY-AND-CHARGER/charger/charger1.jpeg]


<p align="right">
  <a href="#table-of-contents">⬆ Back to Table of Contents</a>
</p>

### 7.6 ON/OFF Button
The buttons used to turn the robot on, start it, and stop it was placed on top to make it easily accessible.

<p>This section explains the code structure and button controls for operating the robot.</p>

<h4 align="center">Code for Buttons</h4>

<p align="center">
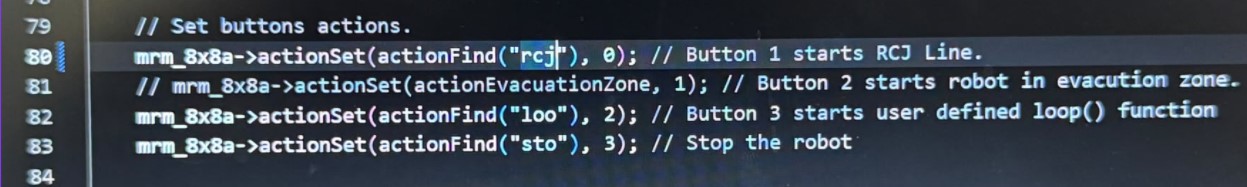
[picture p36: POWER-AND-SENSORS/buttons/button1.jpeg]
Code for Buttons
  
</p>

<p align="center">
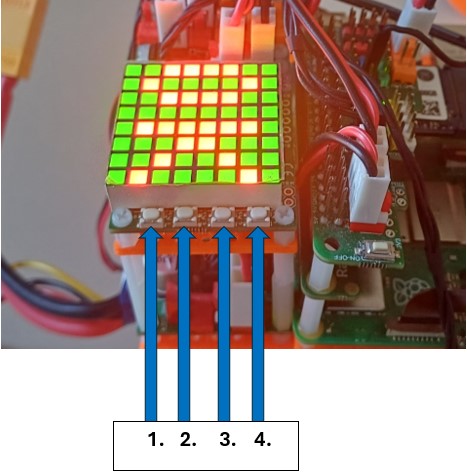
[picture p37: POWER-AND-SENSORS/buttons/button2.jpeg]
Physical Buttons on Robot
  
</p>

<h4>Button Functions</h4>

<p><strong>1. Button 1 (Pin 1) &ndash; Start / Stop:</strong> Launches <code>system_start()</code> or halts the robot with <code>full_stop()</code>.</p>

<p><strong>2. Button 2 (Pin 2) &ndash; Open Challenge:</strong> Selects and starts <code>open_challenge()</code>.</p>

<p><strong>3. Button 3 (Pin 3) &ndash; Obstacle Challenge:</strong> Selects and starts <code>prepreke_challenge()</code>.</p>

<p><strong>4. Button 4 (Pin 4) &ndash; Servo +2°:</strong> Manually increases the servo angle by 2 degrees.</p>

<p align="right">
  <a href="#table-of-contents">⬆ Back to Table of Contents</a>
</p>

## 8. Software Architecture
### 8.1 Overview
The robot software is written in C++. The code is developed and maintained within Visual Studio Code, utilizing dedicated extensions for embedded C++ compilation and debugging. The software architecture handles direct motor control, power management, and timing routines required for accurate motor drive operations.

<p align="right">
  <a href="#table-of-contents">⬆ Back to Table of Contents</a>
</p>

### 8.2 Code
#### Code used for distance sensors
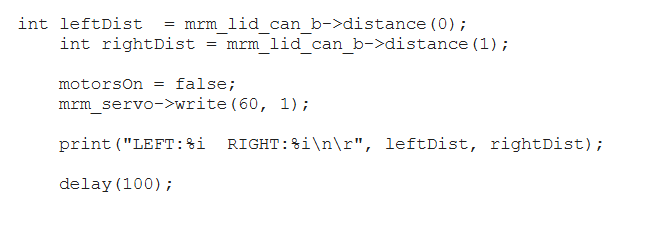
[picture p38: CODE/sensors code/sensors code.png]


#### Code used for camera
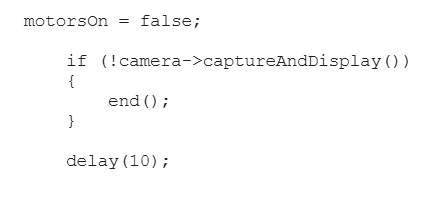
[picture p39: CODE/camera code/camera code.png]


<p align="right">
  <a href="#table-of-contents">⬆ Back to Table of Contents</a>
</p>

[Code](4_vožnja_u_krug_bez_prepreka.txt)

### 8.3 Open Challenge Strategy

The Open Challenge requires the robot to complete three laps of the track autonomously without colliding with obstacles. During the run, the robot uses its LiDAR sensors and camera to detect the track boundaries and nearby objects. Based on the sensor data, the control system continuously adjusts the robot’s direction and movement. The main goal is to achieve reliable navigation, smooth cornering, and consistent obstacle avoidance throughout all three laps.

<p align="right">
  <a href="#table-of-contents">⬆ Back to Table of Contents</a>
</p>

### 8.4 Obstacle Challenge Strategy

<p>The robot uses a <b>Raspberry Pi Camera Module 3</b> connected to a <b>Raspberry Pi 5</b>, enabling image and video capture for line detection, object recognition, and color marker detection. While LiDAR sensors handle wall-following and distance measurement, the camera provides visual perception that distance sensors alone cannot supply. By combining wall-following via LiDAR with visual processing from the camera, the robot actively detects red and green obstacles. The system processes camera data in real time to steer correctly around color-coded markers while maintaining high-speed autonomous navigation. This dual-sensing setup ensures precise positioning and seamless obstacle avoidance required to complete all three laps fully autonomously.</p>

<p align="right">
  <a href="#table-of-contents">⬆ Back to Table of Contents</a>
</p>

## 9. Engineering Decisions
### 9.1 Major Problems and Solutions
#### Connection Failure 

- During development, we experienced repeated problems with the Wi-Fi connection between the robot and the development computer. The connection was unstable and we could not work with the robot properly. To improve reliability, we tested a wired Ethernet connection using an RJ45 network cable. During our tests, this connection proved to be significantly more stable and reliable than Wi-Fi, so we decided to use the wired connection during development.

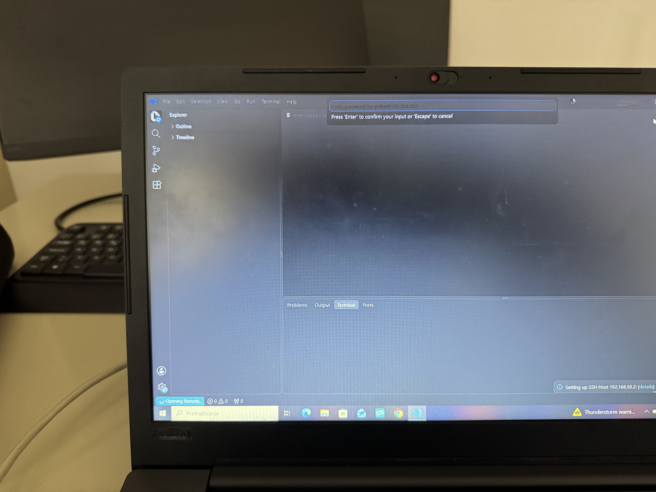
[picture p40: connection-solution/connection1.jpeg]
 
 

#### Sensor Placement

- During testing, the distance sensors were positioned on the upper part of the robot. In this position, the sensors were too high and could not reliably detect the wall directly in front of the vehicle. After identifying this issue, we redesigned the sensor position and moved the distance sensors lower on the chassis. This improved their field of view and allowed them to detect the wall more reliably. This change showed us how sensor placement can affect the performance of the navigation system.

  

**Test result:**
| Sensor position | Successful wall detections |
|---|---:|
| Original higher position | 3/10 |
| Lowered position | 8/10 |

<p align="right">
  <a href="#table-of-contents">⬆ Back to Table of Contents</a>
</p>

## 10. Testing & Results

<p>You can see all the tests and results on our YouTube channel:</p>

<a href="https://www.youtube.com/@mechaminds111" target="_blank">
  MechaMinds Youtube Channel
</a>

<p align="right">
  <a href="#table-of-contents">⬆ Back to Table of Contents</a>
</p>
  
## 11. Components / Bill of Materials

[View the Bill of Materials PDF](docs/bill-of-materials/bill-of-materials.pdf)

<p align="right">
  <a href="#table-of-contents">⬆ Back to Table of Contents</a>
</p>

## 12. Build & Reproduction Guide
Our robot is completely made out of 3D-printed parts.

### 12.1 Parts

All custom mechanical components and structural parts of the robot were designed using Autodesk Fusion and manufactured via 3D printing.
* **3D Modeling & CAD:** Autodesk Fusion
* **Manufacturing:** 3D Printed
* **3D Models & STL Files:**
  * Wheel STL file: [BUILD-GUIDE/wheels/wheel11.stl](BUILD-GUIDE/wheels/wheel1.stl)
  * Chassis STL file: [BUILD-GUIDE/chassis/mrm3d-chmod110-chassis.stl](BUILD-GUIDE/chassis/mrm3d-chmod110-chassis.stl)
  * Raspberry pi3 STL file: [BUILD-GUIDE/Raspberry-pi3/RaspberryPI3.stl](BUILD-GUIDE/Raspberry-pi3/RaspberryPi3.stl)
  * RotaryJointRoundTop STL file: [BUILD-GUIDE/rotaryjoint/RotaryJointRoundTop.stl](BUILD-GUIDE/rotaryjoint/RotaryJointRoundTop.stl)

-**wheels**:

   

<p align="right">
  <a href="#table-of-contents">⬆ Back to Table of Contents</a>
</p>

### 12.2 Assembly

<p align="right">
  <a href="#table-of-contents">⬆ Back to Table of Contents</a>
</p>

## 13. Repository Structure
This repository is organized into separate folders for documentation, hardware, software, media and testing. It makes it easier to locate files needed to understand and reproduce the robot.

```text
WRO/
├── BATTERY-AND-CHARGER/
│   ├── battery/
│   │   ├── battery1.jpeg
│   │   ├── battery2.jpeg
│   │   ├── battery3.jpeg
│   │   └── battery4.jpeg
│   └── charger/
│       └── charger1.jpeg
│
├── BUILD-GUIDE/
│   ├── Raspberry pi3/
│   │   └── RaspberryPi3.stl
│   ├── chassis/
│   │   ├── chassis.stl
│   │   └── mrm3d-chmod110 - chassis.stl
│   ├── panel/
│   │   └── mrm-pl90x35.stl
│   ├── rotaryjoint/
│   │   └── RotaryJointRoundTop.stl
│   ├── wheels-making/
│   │   ├── wheels-fusion.png
│   │   ├── wheels1.jpeg
│   │   ├── wheels2.jpeg
│   │   └── wheels3.jpeg
│   ├── wheels/
│   │   ├── wheel1.stl
│   │   └── wheel5-70.step
│   ├── wiring/
│   │   └── donjaploca.PNG.jpg
│   └── engineering-decisions.md.txt
│
├── CODE/
│   ├── camera code/
│   │   └── camera code.png
│   └── sensors code/
│       └── sensors code.png
│
├── DEVELOPMENT-HISTORY/
│   ├── version_1/
│   │   ├── bottom.jpeg
│   │   ├── front.jpeg
│   │   ├── left.jpeg
│   │   ├── rear.jpeg
│   │   ├── right.jpeg
│   │   └── top.jpeg
│   │
│   ├── version_2/
│   │   ├── build/
│   │   │   ├── build-01.jpeg
│   │   │   ├── build-02.jpeg
│   │   │   ├── build-03.jpeg
│   │   │   ├── build-04.jpeg
│   │   │   ├── build-05.jpeg
│   │   │   └── build-06.jpeg
│   │   └── final/
│   │       ├── bottom.jpeg
│   │       ├── front.jpeg
│   │       ├── left.jpeg
│   │       ├── rear.jpeg
│   │       ├── right.jpeg
│   │       └── top.jpeg
│   │
│   ├── version_3/
│   │   ├── bottom.jpeg
│   │   ├── ford1.jpeg
│   │   ├── ford2.jpeg
│   │   ├── front.jpeg
│   │   ├── left.jpeg
│   │   ├── rear.jpeg
│   │   └── right.jpeg
│   │
│   └── version_4/
│       ├── bottom.jpeg
│       ├── front.jpeg
│       ├── left.jpeg
│       ├── rear.jpeg
│       ├── right.jpeg
│       └── top.jpeg
│
├── POWER-AND-SENSORS/
│   ├── buttons/
│   │   ├── button1.jpeg
│   │   └── button2.jpeg
│   ├── camera/
│   │   └── camera.png
│   ├── motor/
│   │   └── motor.png
│   └── sensors/
│       └── sensor.jpg
│
├── TEAM-PICTURES/
│   ├── funny photo/
│   │   ├── funny photo1.jpeg
│   │   ├── funny photo2.jpeg
│   │   ├── funny photo3.jpeg
│   │   └── funny photo4.jpeg
│   ├── other photos/
│   │   ├── lego - mechaminds.jpg
│   │   ├── team2.jpeg
│   │   ├── team3.JPG
│   │   └── team4.JPG
│   ├── team photo/
│   │   └── team photo.jpeg
│   ├── video/
│   │   ├── video_mechaminds.mp4
│   │   └── video_mechaminds.zip
│   └── school logo.png
│
├── archive/
│   └── first-readme.md.txt
│
├── bill-of-materials/
│   └── bill-of-materials.pdf
│
├── connection-solution/
│   ├── connection1.jpeg
│   ├── connection2.jpeg
│   ├── connection3.jpeg
│   └── connection4.jpeg
│
└── README.md
```

<p align="right">
  <a href="#table-of-contents">⬆ Back to Table of Contents</a>
</p>

## 14. Engineering Journal
With the start of last school year (8.9.2025) we started working with robot [4.1 Version 1](#41-version-1), but the robot was not reliable enough to complete three laps so we decided to change the robot for better performance. 
On 31.3.2026. we started working with [4.2 Version 2](#42-version-2). The robot was working very well but then about one month before the competition we started having problems connecting the robot to Wi-Fi, it started crashing and we tried to find a solution before the competition but we did not succeed. 
So, on 22.5.2026. we built [4.3 Version 3](#43-version-3). The robot had a problem turning its wheels because of the design, so it could not complete even one lap, because of this we had to completely redesign it.
On 6.6.2026. we built [4.4 Version 4](#44-version-4). Although we went to the competition with this robot it still had a few flaws. The LEGO sensors that we used to measure distance were not able to detect walls from sufficient distance so the robot couldn't complete even one lap.
Over the summer we decided that we should fix robot [4.2 Version 2](#42-version-2) so the whole summer we spent working on that robot and fixing it. On 27.8.2026. we connected robot to Wi-Fi and then we got into programming. 

<p align="right">
  <a href="#table-of-contents">⬆ Back to Table of Contents</a>
</p>

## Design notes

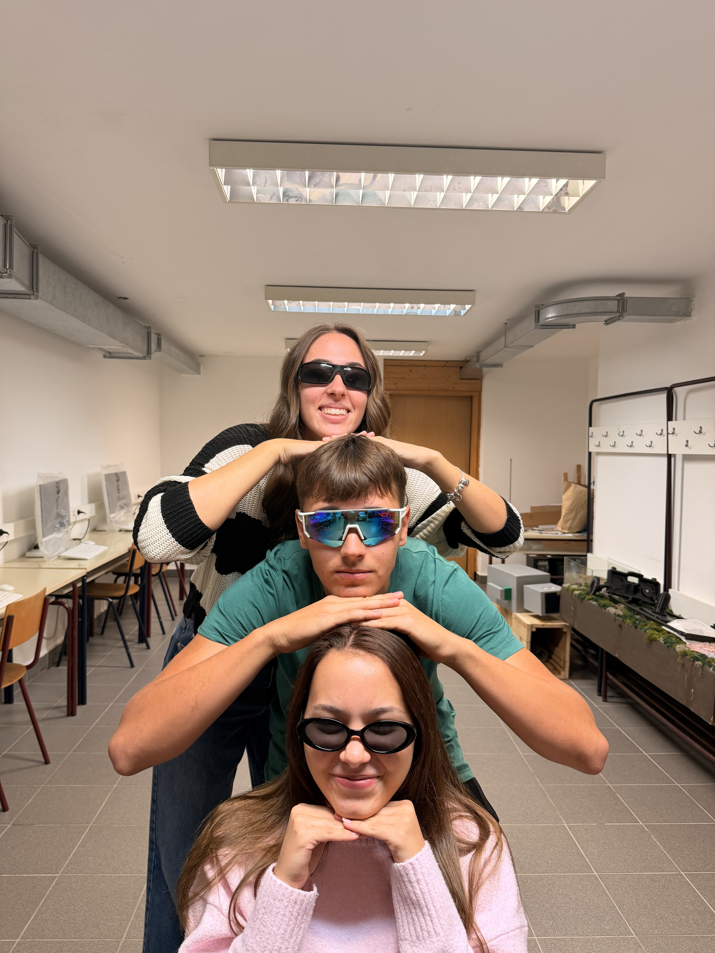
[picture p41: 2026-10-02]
TEAM-PICTURES/funny photo/funny photo4.jpeg

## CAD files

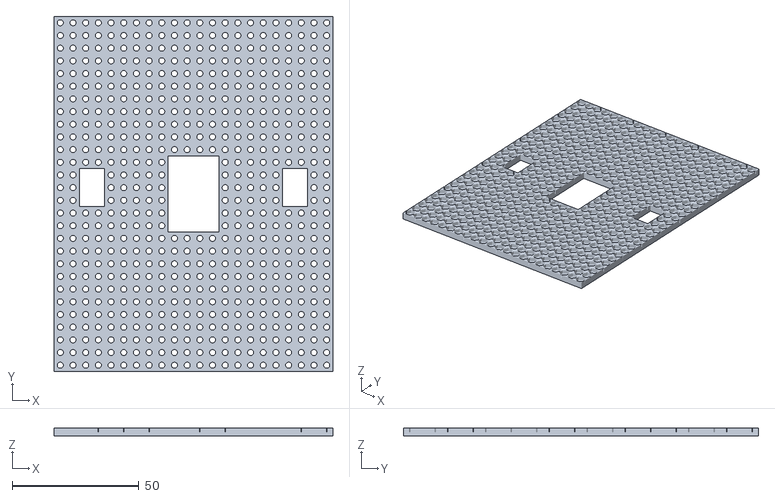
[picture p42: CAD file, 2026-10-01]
BUILD-GUIDE/chassis/mrm3d-chmod110 - chassis.stl
110.0 x 140.0 x 3.30

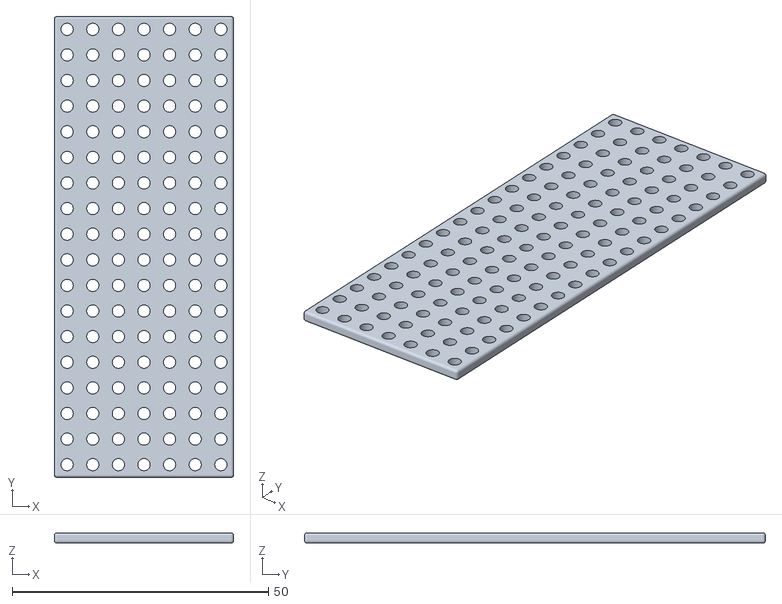
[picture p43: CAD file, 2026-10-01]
BUILD-GUIDE/panel/mrm-pl90x35.stl
35.0 x 90.0 x 2.00

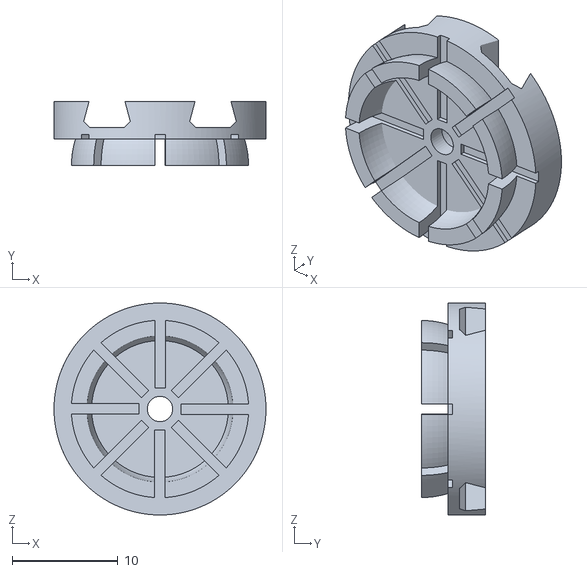
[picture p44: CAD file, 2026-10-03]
BUILD-GUIDE/rotaryjoint/RotaryJointRoundTop.stl
20.0 x 6.00 x 20.0

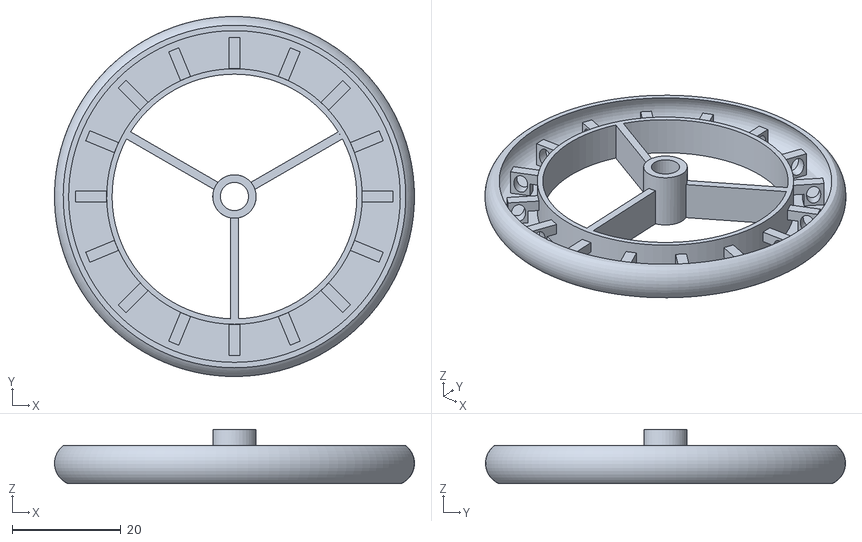
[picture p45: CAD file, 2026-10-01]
BUILD-GUIDE/wheels/wheel1.stl
66.2 x 66.2 x 10.0

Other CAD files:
BUILD-GUIDE/chassis/chassis.stl
BUILD-GUIDE/wheels/wheel5-70.step

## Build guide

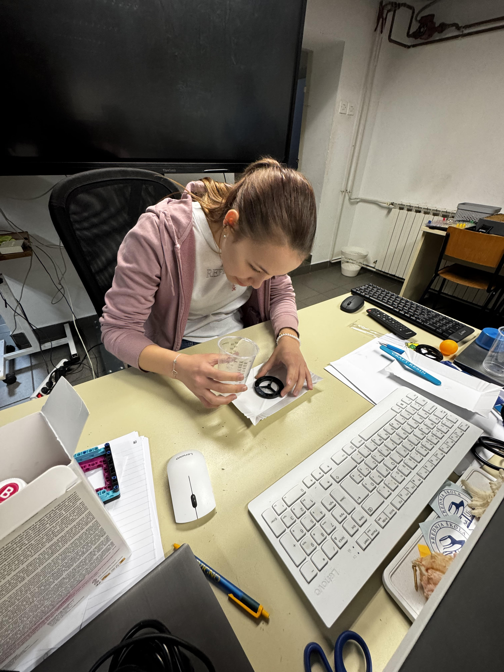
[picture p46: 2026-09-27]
BUILD-GUIDE/wheels-making/wheels1.jpeg

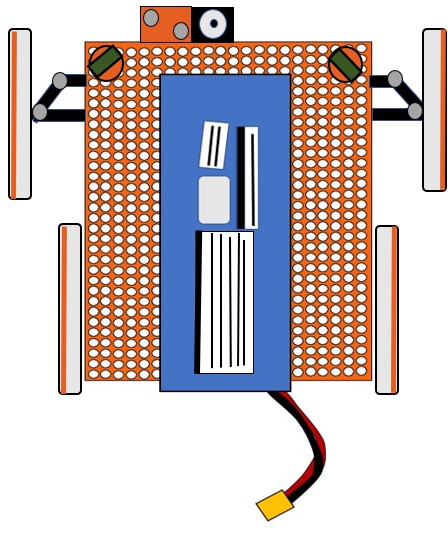
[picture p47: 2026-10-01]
BUILD-GUIDE/wiring/donjaploca.PNG.jpg

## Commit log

2026-09-27 pictures of wheel making process
2026-09-29 Fix link formatting for ON/OFF Button section
2026-09-29 Enhance README with button control details
    Added detailed explanations for button functions and their corresponding actions.
2026-09-30 battery and charger photos upload
2026-09-30 Revise Power Architecture section in README
    Updated section title and added details about the battery and charger used for the robot's power architecture.
2026-09-30 Fix image source for battery4 in README
    Corrected the image source for the fourth battery image in the README.
2026-09-30 Update battery images in README
    Removed one battery image and updated the list of displayed images.
2026-09-30 Specify weight as 0.876 kg in README
    Updated the weight specification in the README.
2026-09-30 Add robot parts section to README
    Added a section about making robot parts, specifically wheels.
2026-09-30 Fix link formatting for wheel STL file in README
2026-09-30 Fix link formatting for wheel STL file
2026-09-30 stl files upload
    [wheel1.stl, wheel5-70.step]
2026-09-30 fusion wheels photo upload
2026-09-30 Refine description of steering system mechanism
    Updated wording for clarity in the steering system section.
2026-10-01 sensor photo upload
2026-10-01 camera pictures upload
2026-10-01 Enhance README with ML-R BDC N20 motor details
    Added details about the ML-R BDC N20 motor, including its specifications and role in the robot's propulsion mechanism.
2026-10-01 Fix formatting of wheels and chassis sections in README
2026-10-01 Add iframe for chassis STL file embedding
2026-10-01 Remove iframe embed code from chassis file
2026-10-01 Enhance obstacle challenge strategy description
    Added details about the robot's dual-sensing setup using a Raspberry Pi Camera Module 3 and LiDAR sensors for obstacle detection and navigation.
2026-10-01 Create chassis
2026-10-01 Remove testing sections from README
    Removed sections for Mechanical and Sensor Tests from the README.
2026-10-01 Eliminate duplicate motor description in README
    Removed duplicate description of the ML-R BDC N20 motor.
2026-10-01 Remove Button 5 description from README
    Removed description for Button 5 functionality.
2026-10-01 Update chassis
2026-10-01 reconstructing maps
    [wheel1.stl, wheel5-70.step]
2026-10-01 Rename mrm3d-chmod110 - chassis.stl to chassis.stl
    [chassis.stl, mrm3d-chmod110 - chassis.stl]
2026-10-01 Rename chassis.stl to mrm3d-chmod110 - chassis.stl
    [mrm3d-chmod110 - chassis.stl]
2026-10-01 Update chassis STL file link in README
2026-10-01 Fix typo in Steering & Driving System heading
2026-10-01 Update image paths for battery images in README
2026-10-01 Fix image source path for button2 in README
2026-10-03 Enhance README with steering system details
    Added details about the steering system and clarified the role of the rear wheels and motor in the robot's movement.
2026-10-03 Add section for distance sensors code in README
2026-10-03 Add image for distance sensors code section
2026-10-03 Add RotaryJointRoundTop STL file link to README
2026-10-03 Add wiring diagram section to README
    Added a section explaining the wiring diagram of the robot.
2026-10-04 code and wiring docs update
